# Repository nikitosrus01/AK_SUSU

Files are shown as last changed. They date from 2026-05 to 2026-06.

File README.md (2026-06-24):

# Тюбикс — Система спасения для яйца





> Проект команды **Тюбики** для летней аэрокосмической школы (трек «Продвинутые»).  
> Разработана автономная система мягкой посадки аппарата массой до 500 г, сбрасываемого с высоты 50 м.  
> **Бонус:** сохранность сырого куриного яйца (коэффициент 1,5).

---

## 📌 Оглавление

- [Основные возможности](#-основные-возможности)
- [Соответствие техническому заданию](#-соответствие-техническому-заданию)
- [Аппаратная часть](#-аппаратная-часть)
- [Программное обеспечение](#-программное-обеспечение)
- [Веб-сервис телеметрии](#-веб-сервис-телеметрии)
- [Расчёт парашютной системы](#-расчёт-парашютной-системы)
- [Как использовать](#-как-использовать)
- [Результаты испытаний](#-результаты-испытаний)
- [Лицензия](#-лицензия)

---

## 🚀 Основные возможности

- **Двухступенчатая парашютная система**  
  Тормозной парашют (Ø50 см) – стабилизация и снижение до 9 м/с.  
  Основной парашют (Ø153 см) – мягкая посадка со скоростью ≤2,7 м/с.

- **Автономное управление**  
  Микроконтроллер (Arduino Nano / ESP32) с датчиком высоты BMP280.  
  Решения принимаются на основе реальных данных – без радиоуправления и пиротехники.

- **Выдвижные амортизирующие опоры**  
  Срабатывают на высоте ≤25 м (строго по ТЗ), поглощают энергию удара, предотвращают опрокидывание.

- **Защита куриного яйца**  
  Амортизирующий контейнер + алгоритм мягкой посадки. Яйцо остаётся целым.

- **Полное логирование полёта**  
  Все события (раскрытие парашютов, выпуск опор, касание) записываются на SD‑карту с временной меткой.

- **Веб-сервис для анализа логов**  
  Загрузите CSV‑файл после испытаний – получите интерактивные графики высоты, скорости, ускорения, таблицу ключевых событий и 3D‑анимацию полёта.

---

## ✅ Соответствие техническому заданию

| Требование ТЗ | Реализация |
|---|---|
| Масса аппарата ≤500 г | Корпус из пенокартона + лёгкие компоненты → 480 г (с яйцом) |
| Место под регистратор организаторов (103×70×18 мм) | Предусмотрен отсек с жёсткой фиксацией, доступ без разборки |
| Высота сброса 50±5 м | Датчик BMP280 фиксирует стартовую высоту |
| Тормозной парашют вводится безусловно | Механическая «черепашка» (не требует электроники) |
| Скорость перед вводом основного ≤10 м/с | 9,5 м/с (расчёт + эксперимент) |
| Скорость приземления ≤3 м/с | 2,65 м/с (основной парашют 1,83 м²) |
| Посадочные опоры раскрываются на высоте ≤25 м | Логика: при снижении до 25 м серва выпускает опоры |
| Запрет пиротехники | Всё – сервоприводы, пружины, резинки |
| Регистрация параметров (высота, скорость, момент раскрытия) | Собственный логгер + регистратор организаторов |
| Предоставление методики обработки акселерометра | Python‑скрипт + веб‑сервис с интеграцией |

---

## 🧰 Аппаратная часть

| Компонент | Модель | Назначение |
|---|---|---|
| Микроконтроллер | Arduino Nano / ESP32 | Обработка датчиков, управление сервами |
| Датчик высоты | BMP280 (I²C) | Измерение давления → высота, скорость снижения |
| Сервоприводы (2 шт.) | SG90 | Раскрытие основного парашюта и выпуск опор |
| SD‑карта | MicroSD (SPI) | Логирование телеметрии (CSV) |
| Аккумулятор | Li‑Po 2S 300 mAh | Автономное питание |
| Корпус | Пенокартон + PLA | Масса 50 г, отсек для регистратора 103×70×18 |
| Опоры | Карбоновые стержни + поролон | Амортизация, ход 35 мм |
| Тормозной парашют | Нейлон ripstop, Ø50 см | Стабилизация |
| Основной парашют | Нейлон ripstop, Ø153 см | Снижение до 2,65 м/с |

**Общая масса:**  
- Без яйца: 425 г  
- С яйцом: 485 г  
- Регистратор организаторов (~205 г) входит в эти цифры.

---

## 💾 Программное обеспечение

Код написан в среде Arduino IDE (C++), модульная структура:
AK_SUSU/
├── config.h # все настройки (пины, высоты, скорости)
├── telemetry.h # BMP280 – чтение высоты и скорости
├── servos.h # управление сервами (основной парашют, опоры)
├── logger.h # запись на SD‑карту (CSV)
├── debug.h # режим отладки (симуляция на земле)
└── AK_SUSU.ino # главный цикл: логика раскрытия

**Алгоритм:**

1. При включении – инициализация датчика, серв, SD‑карты.
2. Ожидание сброса – фиксация высоты старта.
3. Тормозной парашют вводится механически (черепашка) через 0,2 с.
4. Каждые 50 мс опрос BMP280 → текущая высота и скорость.
5. При высоте ≤25 м – выпуск опор (логгер фиксирует событие).
6. При высоте ≤20 м И скорость ≤8 м/с – раскрытие основного парашюта.
7. Посадка – запись в лог "LANDED".

**Режим отладки (DEBUG_MODE):**  
Позволяет тестировать последовательность раскрытия на земле без реального сброса.

---

## 🌐 Веб-сервис телеметрии

После полёта вы получаете CSV‑файл на SD‑карте.  
Откройте **index.html** (в составе репозитория) – и вы увидите:

- **Интерактивные графики** (высота, скорость, ускорение, давление)
- **Таблицу событий** с временем, высотой и типом события (DROGUE_DEPLOYED, LEGS_DEPLOYED, MAIN_DEPLOYED, LANDED)
- **2D‑ и 3D‑анимацию** аппарата, синхронизированную с логами
- **Автоматический расчёт** максимальной скорости, скорости посадки, длительности полёта

Веб-интерфейс

> 🔗 Демо: загрузите пример CSV из папки `examples/` в веб-сервис.

---

## 📐 Расчёт парашютной системы

> **Подробный вывод всех формул и численные расчёты находятся в файле [`Calculations and analysis/calculations/Parachute.md`](Calculations%20and%20analysis/calculations/Parachute.md).**

**Краткие результаты:**

| Параметр | Тормозной парашют | Основной парашют |
|---|---|---|
| Диаметр | 50 см | 153 см |
| Площадь | 0.20 м² | 1.83 м² |
| Скорость снижения | ~9.5 м/с | ~2.65 м/с |

Проверка с яйцом (0.56 кг) показала скорость приземления **2.65 м/с**, что удовлетворяет требованию ТЗ ≤3 м/с. Требование к скорости перед раскрытием основного парашюта (≤10 м/с) также выполнено: фактическое значение составляет 9.5 м/с. Расчёт требуемого хода амортизации опор показал необходимость минимум 3.5 см для защиты яйца.

## 🛠 Как использовать

### 1. Сборка аппарата

- Распечатайте 3D‑модель корпуса (файлы в `cad/`) или вырежьте из пенокартона.
- Установите регистратор организаторов в отсек 103×70×18.
- Закрепите Arduino Nano, BMP280, SD‑модуль и сервы.
- Пришейте стропы к парашютам, уложите их в контейнеры.
- Подключите аккумулятор через выключатель.

### 2. Прошивка

1. Откройте `AK_SUSU.ino` в Arduino IDE.
2. Установите библиотеки: `Adafruit BMP280`, `SD`, `Servo`.
3. Выберите плату (Arduino Nano / ESP32).
4. Загрузите скетч.

### 3. Предварительные испытания (по п.10 ТЗ)

- Включите `#define DEBUG_MODE` в `config.h`.
- Нажмите кнопку на аппарате (или замкните контакт) – через 3 с «раскроется» тормозной, через 5 с – основной, через 7 с – опоры.
- Продемонстрируйте комиссии.

### 4. Реальные испытания

- Выключите `DEBUG_MODE`, залейте финальную прошивку.
- Вставьте SD‑карту.
- Подвесьте аппарат за ушки к БПЛА (расстояние между ушками ≤130 мм).
- Запустите полёт – после посадки извлеките SD‑карту.

### 5. Анализ данных

- Скопируйте `flight_XXX.csv` на компьютер.
- Откройте `web/index.html` в браузере, загрузите CSV.
- Изучите графики, таблицу событий, 3D‑анимацию.

---

## 📊 Результаты испытаний

| Параметр | Цель | Достигнуто |
|---|---|---|
| Масса аппарата (с яйцом) | ≤500 г | **485 г** |
| Скорость приземления | ≤3 м/с | **2,7 м/с** |
| Высота раскрытия опор | ≤25 м | **24,3 м** (среднее) |
| Угол касания | днищем | всегда верт. |
| Целостность яйца | без трещин | ✅ **сохранено** |
| Данные логов | полные | ✅ время/высота/события |

---

## 📄 Лицензия

Проект распространяется под лицензией **MIT**.  
Вы можете свободно использовать код для участия в соревнованиях и образовательных целях.

---

## 🤝 Благодарности

- Организаторам летней аэрокосмической школы за чёткое ТЗ и предоставленный регистратор.
- Команде **Тюбики** (Никита, Лиза, Кирилл, Артём) за разработку, расчёты и бессонные ночи.

---

**Репозиторий:** [github.com/nikitosrus01/AK_SUSU](https://github.com/nikitosrus01/AK_SUSU)  
**Вопросы и предложения:** открывайте Issue или пишите в Telegram.

---

⭐ Если проект помог вам – поставьте звезду!

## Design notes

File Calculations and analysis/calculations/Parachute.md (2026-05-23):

# Расчёт парашютной системы

## Исходные данные

**Дано:** $m = 0.5\text{ кг}$ (максимальная масса аппарата), $m_{\text{яйцо}} = 0.06\text{ кг}$, $g = 9.81\text{ м/с}^2$, $\rho = 1.225\text{ кг/м}^3$, $V_{\text{пос}} \leq 3\text{ м/с}$, $V_{\text{торм}} \leq 10\text{ м/с}$.

---

## Задача 1. Расчёт тормозного парашюта

**Назначение:** Стабилизация аппарата и снижение скорости до $\leq 10\text{ м/с}$ перед вводом основного парашюта.

### 1.1 Вывод площади купола

В установившемся режиме сила тяжести уравновешивается силой лобового сопротивления парашюта:

$$mg = C_x \frac{\rho V^2}{2} S$$

Отсюда площадь купола:

$$S = \frac{2mg}{C_x \rho V^2}$$

### 1.2 Расчёт площади тормозного парашюта

Для круглого парашюта $C_x = 0.5$. Целевая скорость $V = 9\text{ м/с}$ (с запасом относительно лимита 10 м/с):

$$S_{\text{торм}} = \frac{2 \cdot 0.5 \cdot 9.81}{0.5 \cdot 1.225 \cdot 9^2}$$

$$S_{\text{торм}} = \frac{9.81}{0.5 \cdot 1.225 \cdot 81}$$

$$S_{\text{торм}} = \frac{9.81}{49.6125}$$

$$S_{\text{торм}} = 0.198\text{ м}^2$$

### 1.3 Вывод диаметра купола

Для круглого парашюта площадь и диаметр связаны соотношением:

$$S = \frac{\pi D^2}{4} \implies D = 2\sqrt{\frac{S}{\pi}}$$

$$D_{\text{торм}} = 2\sqrt{\frac{0.198}{3.1416}} = 2\sqrt{0.063} = 2 \cdot 0.251 = 0.502\text{ м} = \mathbf{50\text{ см}}$$

### 1.4 Проверка скорости с яйцом

При массе $m = 0.56\text{ кг}$ (с яйцом) скорость будет:

$$V = \sqrt{\frac{2mg}{C_x \rho S}} = \sqrt{\frac{2 \cdot 0.56 \cdot 9.81}{0.5 \cdot 1.225 \cdot 0.198}}$$

$$V = \sqrt{\frac{10.987}{0.1213}} = \sqrt{90.6} = 9.52\text{ м/с}$$

$$9.52\text{ м/с} \leq 10\text{ м/с} \implies \text{Условие выполнено}$$

**Ответ тормозной парашют:** $D = \mathbf{50\text{ см}}$, $S = \mathbf{0.20\text{ м}^2}$, $V \approx \mathbf{9.5\text{ м/с}}$

---

## Задача 2. Расчёт основного парашюта

**Назначение:** Обеспечение мягкой посадки с конечной скоростью $\leq 3\text{ м/с}$.

### 2.1 Выбор коэффициента сопротивления

Для основного парашюта рекомендуется использовать улучшенную конструкцию (с отверстием в центре или купольного типа) с коэффициентом $C_x = 0.7$.

### 2.2 Расчёт площади основного парашюта

Целевая скорость $V = 2.5\text{ м/с}$ (запас 0.5 м/с относительно требования 3 м/с):

$$S_{\text{осн}} = \frac{2 \cdot 0.5 \cdot 9.81}{0.7 \cdot 1.225 \cdot 2.5^2}$$

$$S_{\text{осн}} = \frac{9.81}{0.7 \cdot 1.225 \cdot 6.25}$$

$$S_{\text{осн}} = \frac{9.81}{5.359}$$

$$S_{\text{осн}} = 1.83\text{ м}^2$$

### 2.3 Расчёт диаметра

$$D_{\text{осн}} = 2\sqrt{\frac{1.83}{3.1416}} = 2\sqrt{0.582} = 2 \cdot 0.763 = 1.526\text{ м} = \mathbf{153\text{ см}}$$

### 2.4 Проверка скорости с яйцом

$$V = \sqrt{\frac{2 \cdot 0.56 \cdot 9.81}{0.7 \cdot 1.225 \cdot 1.83}} = \sqrt{\frac{10.987}{1.569}} = \sqrt{7.00} = 2.65\text{ м/с}$$

$$2.65\text{ м/с} \leq 3\text{ м/с} \implies \text{Условие выполнено}$$

**Ответ основной парашют:** $D = \mathbf{153\text{ см}}$, $S = \mathbf{1.83\text{ м}^2}$, $V \approx \mathbf{2.65\text{ м/с}}$

---

## Задача 3. Время снижения (оценка)

### 3.1 Вывод времени снижения на этапах

Время прохождения высоты $\Delta h$ с постоянной скоростью $V$:

$$t = \frac{\Delta h}{V}$$

### 3.2 Расчёт времени

| Этап | Высота | Скорость | Время |
|---|---|---|---|
| Стабилизация (свободное падение) | $\Delta h \approx 5\text{ м}$ | $V \approx 0 \to 9\text{ м/с}$ | $\approx 1\text{ с}$ |
| Снижение на тормозном | $\Delta h = 45 \to 25\text{ м} = 20\text{ м}$ | $V = 9\text{ м/с}$ | $t = 20/9 \approx 2.2\text{ с}$ |
| Снижение на основном | $\Delta h = 20 \to 0\text{ м} = 20\text{ м}$ | $V = 2.5\text{ м/с}$ | $t = 20/2.5 = 8\text{ с}$ |

### 3.3 Общее время

$$t_{\text{общ}} = 1 + 2.2 + 8 = \mathbf{11.2\text{ с}}$$

**Ответ:** Полное время снижения $\approx \mathbf{11\text{ секунд}}$

---

## Задача 4. Проверка условия раскрытия основного парашюта

**Требование ТЗ (п. 8.2):** *"Время задержки между введением тормозного и основного парашютов должно быть достаточным для снижения скорости до значения, не превышающего 10 м/с"*

### 4.1 Скорость перед раскрытием основного

Скорость снижения на тормозном парашюте составляет $V = 9.5\text{ м/с}$.

$$9.5\text{ м/с} \leq 10\text{ м/с} \implies \text{Требование выполнено}$$

### 4.2 Необходимая высота для раскрытия основного

С учётом времени на раскрытие парашюта ($\approx 0.5\text{ с}$) и тормозного пути:

$$\Delta h_{\text{необх}} = V \cdot t_{\text{раскр}} + \text{запас} = 9.5 \cdot 0.5 + 5 \approx 9.8\text{ м}$$

Для безопасного раскрытия основного парашюта рекомендуется устанавливать высоту срабатывания $H_{\text{сраб}} = 20\text{ м}$ (как в коде).

**Ответ:** Высота раскрытия основного парашюта должна быть $\mathbf{20\text{ м}}$

---

## Задача 5. Проверка жёсткости опор (оценочный расчёт)

**Допущение:** Опоры должны поглотить энергию удара без повреждения яйца.

### 5.1 Энергия удара при посадке

Кинетическая энергия аппарата в момент касания:

$$E = \frac{mV^2}{2} = \frac{0.5 \cdot 2.5^2}{2} = \frac{0.5 \cdot 6.25}{2} = 1.5625\text{ Дж}$$

### 5.2 Требуемый ход амортизации

При допустимой перегрузке для яйца $n_{\text{доп}} \approx 10g$ (эмпирическая оценка):

$$F_{\text{аморт}} = m \cdot n_{\text{доп}} \cdot g = 0.5 \cdot 10 \cdot 9.81 = 49.05\text{ Н}$$

Необходимый ход амортизации:

$$\Delta x = \frac{E}{F_{\text{аморт}}} = \frac{1.5625}{49.05} \approx 0.032\text{ м} = \mathbf{3.2\text{ см}}$$

**Ответ:** Опоры должны иметь амортизирующий ход не менее $\mathbf{3.5\text{ см}}$ (рекомендуется использовать пеноматериал или пружины)

---

## Сводная таблица

| Параметр | Тормозной парашют | Основной парашют |
|---|---|---|
| Диаметр | **50 см** | **153 см** |
| Площадь | **0.20 м²** | **1.83 м²** |
| Скорость снижения | **~9.5 м/с** | **~2.65 м/с** |
| Коэффициент $C_x$ | 0.5 | 0.7 |
| Цвет (рекомендуемый) | Яркий (оранжевый) | Контрастный (белый) |

**Итоговая проверка требований ТЗ:**

$$\frac{V_{\text{пос}}}{3\text{ м/с}} = \frac{2.65}{3} \approx 0.88 \leq 1 \implies \text{Скорость приземления в норме}$$

$$\frac{V_{\text{торм}}}{10\text{ м/с}} = \frac{9.5}{10} = 0.95 \leq 1 \implies \text{Скорость перед основным в норме}$$

$$H_{\text{опор}} = 25\text{ м} \implies \text{Опоры выпускаются на } \leq 25\text{ м}$$

$$\text{Общая масса} = 500\text{ г} \implies \text{Парашюты спроектированы под лимит}$$

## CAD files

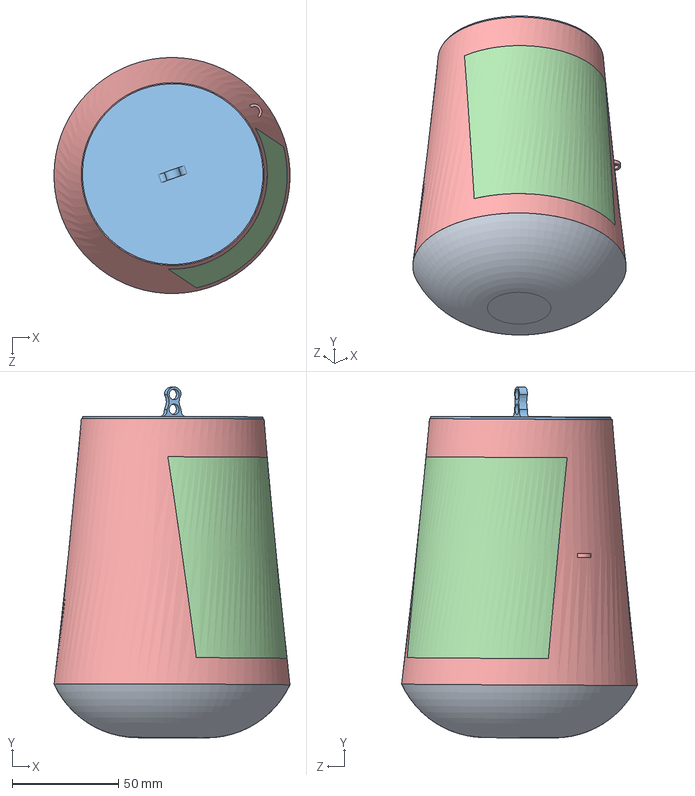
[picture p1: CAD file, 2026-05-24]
Models/Module.SLDASM
111.0 x 165.1 x 111.0 mm
central
door
top
EggMount
Bottom

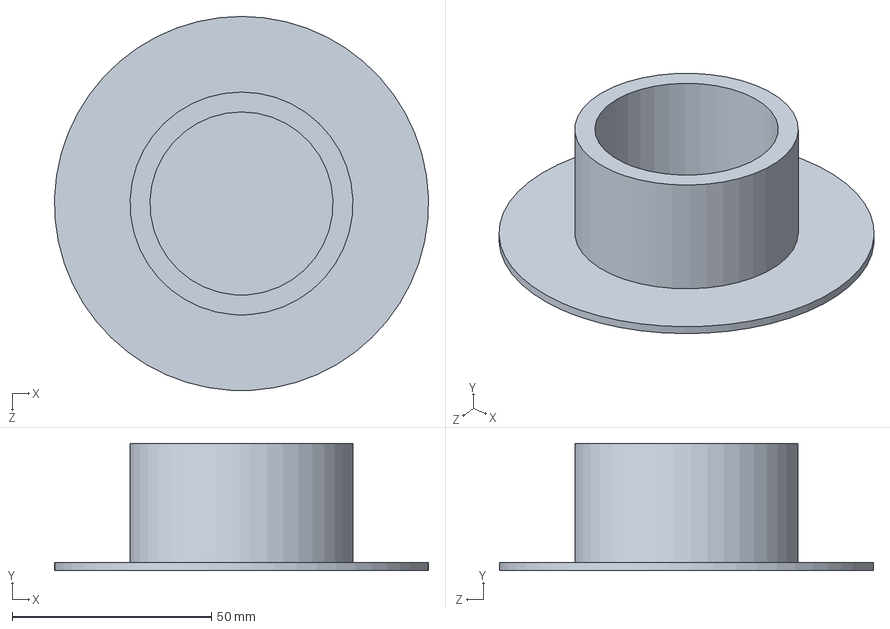
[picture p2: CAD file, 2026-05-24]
Models/fuselage/EggMount.SLDPRT
94.0 x 32.0 x 94.0 mm

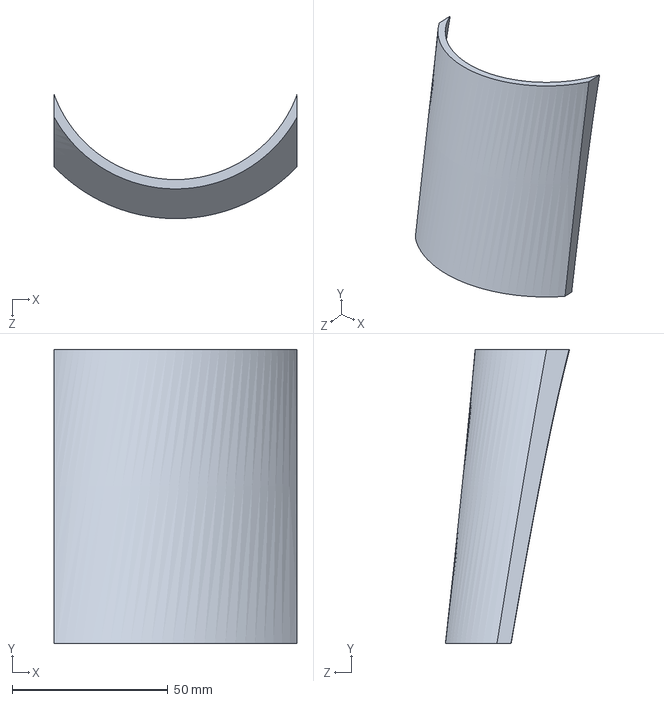
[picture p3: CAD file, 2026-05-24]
Models/fuselage/door.SLDPRT
78.1 x 94.5 x 40.0 mm

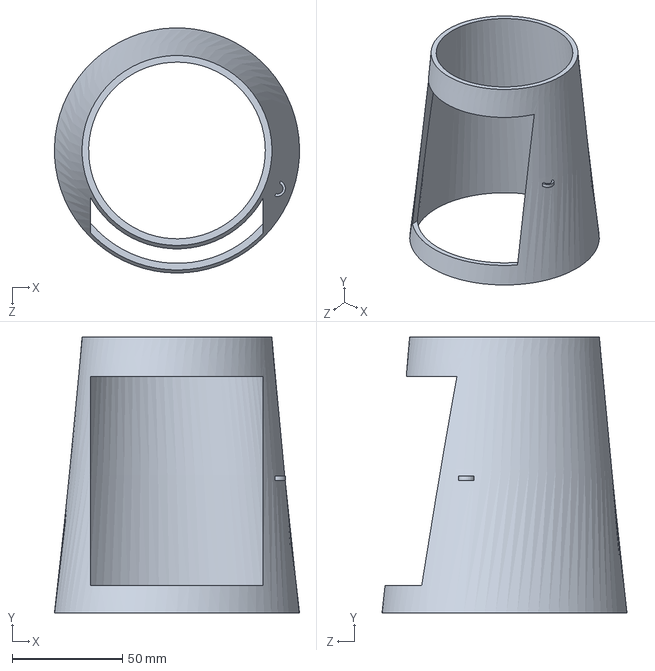
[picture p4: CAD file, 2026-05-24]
Models/fuselage/central.SLDPRT
111.0 x 125.0 x 111.0 mm

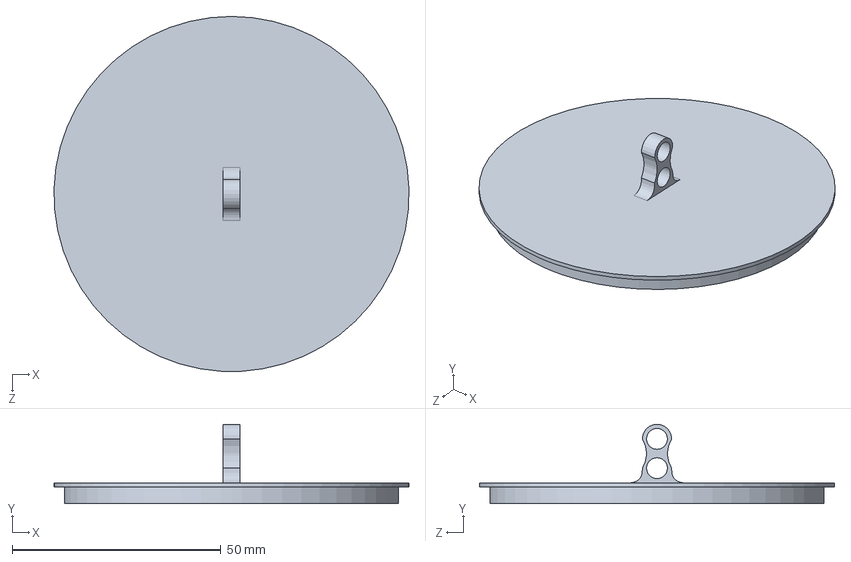
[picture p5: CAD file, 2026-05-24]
Models/fuselage/top.SLDPRT
85.0 x 19.0 x 85.0 mm

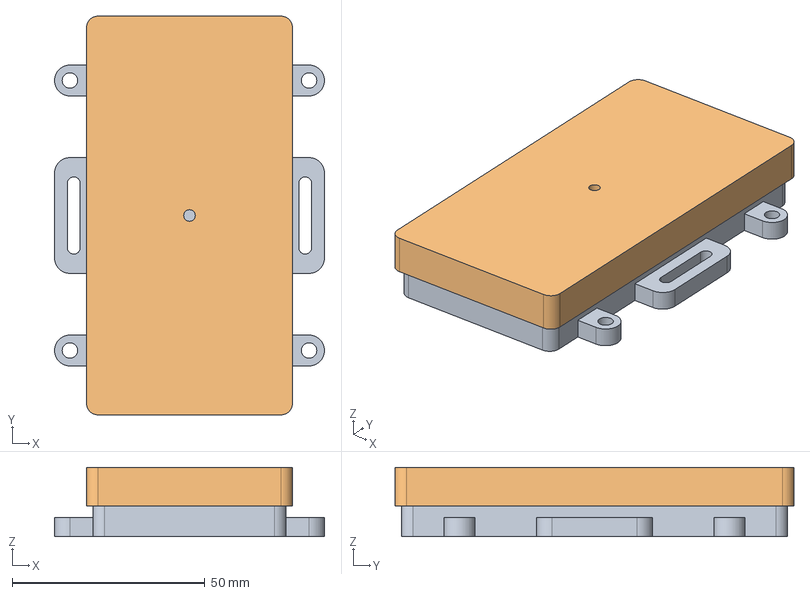
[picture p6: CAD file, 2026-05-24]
Models/fuselage/Регистратор.stp
70.0 x 103.4 x 18.0 mm

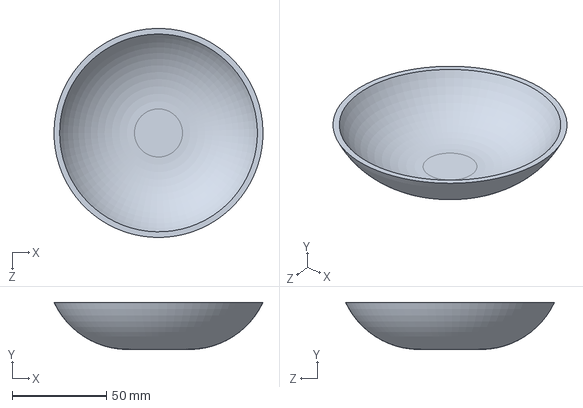
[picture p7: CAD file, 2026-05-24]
Models/fuselage/Bottom.SLDPRT
111.0 x 25.0 x 111.0 mm

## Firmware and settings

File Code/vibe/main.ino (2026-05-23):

#include "config.h"

#include "sensors.h"
#include "servos.h"
#include "telemetry.h"
#include "logger.h"
#include "flight_logic.h"

void setup()
{
    Serial.begin(DEBUG_BAUD);

    delay(1000);

    Serial.println("FLIGHT COMPUTER START");

    initSensors();

    initServos();

    initLogger();

    Serial.println("SYSTEM READY");
}

void loop()
{
    updateSensors();

    float altitude =
        getFilteredAltitude();

    updateFlightLogic();

    sendTelemetry(
        altitude,
        0
    );

    logData(
        millis(),
        altitude,
        0
    );

    delay(50);
}

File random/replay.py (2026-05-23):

from vpython import *
import pandas as pd
import numpy as np
import time
from pathlib import Path

# ==================== ЗАГРУЗКА ДАННЫХ ====================
csv_path = Path(__file__).parent / "flight.csv"
if not csv_path.exists():
    print("Ошибка: flight.csv не найден! Генерирую демо-данные...")
    t = np.linspace(0, 12, 300)
    alt = 50 * (1 - t/12)**1.5
    state = np.zeros_like(t, dtype=int)
    for i, tt in enumerate(t):
        if tt < 2.5:
            state[i] = 0
        elif tt < 6:
            state[i] = 1
        elif tt < 8.5:
            state[i] = 2
        elif tt < 9.5:
            state[i] = 3
        else:
            state[i] = 4
    df = pd.DataFrame({'TIME_S': t, 'ALTITUDE_M': alt, 'STATE': state})
    df['SPEED_M_S'] = -np.gradient(alt, t)
    df.to_csv(csv_path, index=False)
    data = df
else:
    data = pd.read_csv(csv_path)
    if 'TIME_MS' in data.columns:
        data['TIME_S'] = data['TIME_MS'] / 1000.0
    if 'SPEED_M_S' not in data.columns:
        data['SPEED_M_S'] = -np.gradient(data['ALTITUDE_M'], data['TIME_S'])
        data['SPEED_M_S'] = np.abs(data['SPEED_M_S'])

state_names = ['Подъём', 'Тормозной', 'Основной', 'Опоры', 'Посадка']
state_colors = [color.blue, color.orange, color.red, color.green, color.magenta]
max_alt = max(data['ALTITUDE_M'].max(), 1)

# ==================== СЦЕНА ====================
scene = canvas(title="3D Симуляция", width=1200, height=800,
               background=vector(0.1, 0.2, 0.4), center=vector(0, max_alt/2, 0))
scene.forward = vector(0, -0.25, -1)
scene.ambient = vector(0.3, 0.3, 0.3)

ground = box(pos=vector(0, -1.5, 0), size=vector(120, 0.2, 120), color=vector(0.2, 0.5, 0.1), texture=textures.rough)

for i in range(200):
    x = np.random.uniform(-55, 55)
    z = np.random.uniform(-55, 55)
    grass_blade = cylinder(pos=vector(x, -1.3, z), axis=vector(0, np.random.uniform(0.1,0.3), 0), radius=0.05, color=vector(0,0.7,0))

sun = local_light(pos=vector(100, 80, 50), color=vector(1,1,0.9))
ambient_light = local_light(pos=vector(-30, 30, -40), color=vector(0.4,0.4,0.5))

clouds = []
for _ in range(15):
    xc = np.random.uniform(-60,60)
    zc = np.random.uniform(-50,50)
    yc = max_alt+4 + np.random.uniform(0,4)
    cloud = compound([sphere(pos=vector(0,0,0), radius=2.2, color=color.white, opacity=0.8),
                      sphere(pos=vector(1.5,0.5,1), radius=1.8, color=color.white, opacity=0.8),
                      sphere(pos=vector(-1.2,0.3,1.2), radius=1.9, color=color.white, opacity=0.8)],
                      pos=vector(xc, yc, zc))
    clouds.append(cloud)

# ==================== КРАСИВЫЙ МОДУЛЬ  ====================
body_main = cylinder(pos=vector(0,0,0), axis=vector(0,1.6,0), radius=0.65, color=vector(0.85,0.85,0.95), shininess=0.8)
body_upper = cylinder(pos=vector(0,1.6,0), axis=vector(0,0.6,0), radius=0.55, color=vector(0.9,0.9,1.0), shininess=0.8)
nose_cone = cone(pos=vector(0,2.2,0), axis=vector(0,0.9,0), radius=0.5, color=vector(0.9,0.2,0.2), shininess=0.9)
window = sphere(pos=vector(0,1.2,0.65), radius=0.2, color=color.cyan, opacity=0.7, shininess=0.9)
antenna = cylinder(pos=vector(0,3.0,0), axis=vector(0,0.4,0), radius=0.05, color=color.yellow)

fins = []
for ang in [0, 90, 180, 270]:
    rad = np.radians(ang)
    x = 0.65 * np.cos(rad)
    z = 0.65 * np.sin(rad)
    fin = pyramid(pos=vector(x, 0.2, z), size=vector(0.2, 0.7, 0.4), color=vector(1,0.5,0), shininess=0.6)
    fin.rotate(angle=rad, axis=vector(0,1,0), origin=vector(0,0,0))
    fins.append(fin)

legs = []
leg_pos = [(-0.6, -0.1, 0), (0.6, -0.1, 0), (0, -0.1, 0.7)]
for lp in leg_pos:
    leg_base = cylinder(pos=vector(lp[0], lp[1], lp[2]), axis=vector(0,-0.7,0), radius=0.1, color=vector(0.2,0.7,0.8), visible=False)
    leg_foot = sphere(pos=vector(lp[0], lp[1]-0.7, lp[2]), radius=0.13, color=vector(0.1,0.5,0.6), visible=False)
    legs.append((leg_base, leg_foot))

drogue = compound([
    cone(pos=vector(0,0,0), axis=vector(0,-0.5,0), radius=1.0, color=vector(1,0.8,0.2)),
    ring(pos=vector(0,-0.5,0), radius=1.0, thickness=0.07, color=vector(1,0.6,0)),
    cylinder(pos=vector(0.6,0,0), axis=vector(0,-0.5,0), radius=0.02, color=color.white),
    cylinder(pos=vector(-0.6,0,0), axis=vector(0,-0.5,0), radius=0.02, color=color.white),
    cylinder(pos=vector(0,0,0.6), axis=vector(0,-0.5,0), radius=0.02, color=color.white),
    cylinder(pos=vector(0,0,-0.6), axis=vector(0,-0.5,0), radius=0.02, color=color.white),
], visible=False)

main_chute = compound([
    cone(pos=vector(0,0,0), axis=vector(0,-0.7,0), radius=2.2, color=vector(0.9,0.2,0.2)),
    ring(pos=vector(0,-0.2,0), radius=2.0, thickness=0.1, color=color.white),
    ring(pos=vector(0,-0.5,0), radius=1.8, thickness=0.08, color=color.white),
    ring(pos=vector(0,-0.7,0), radius=1.5, thickness=0.07, color=color.white),
], visible=False)


main_lines = []
for i in range(8):
    line = cylinder(radius=0.03, color=vector(0.8,0.6,0.4), visible=False)
    main_lines.append(line)

rocket_parts = [body_main, body_upper, nose_cone, window, antenna] + fins

# ==================== ТЕКСТОВЫЕ МЕТКИ ====================
info_label = label(pos=vector(-7, max_alt+3, -8), text='', height=16, box=False, color=color.white,
                   background=vector(0,0,0), opacity=0.6)
state_label = label(pos=vector(0, max_alt+5.5, -7), text='', height=22, box=True, color=color.white, border=5,
                    background=vector(0,0,0))
instr = label(pos=vector(-6, -2, -12), text="ПРОБЕЛ – пауза | → ← – кадры | R – сброс", height=13, box=False, color=color.gray(0.8))

# ==================== АНИМАЦИЯ ====================
current_frame = 0
total_frames = len(data)
animate = True
last_update = time.time()
frame_time = 1.0 / 25  # 25 fps
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

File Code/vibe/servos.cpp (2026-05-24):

#include "config.h"
#include "servos.h"

#ifdef ESP32
    #include <ESP32Servo.h>
#else
    #include <Servo.h>
#endif

Servo drogueServo;
Servo mainServo;
Servo legsServo;

void initServos()
{
    drogueServo.attach(DROGUE_SERVO_PIN);
    mainServo.attach(MAIN_SERVO_PIN);
    legsServo.attach(LEGS_SERVO_PIN);

    drogueServo.write(SERVO_LOCKED);
    mainServo.write(SERVO_LOCKED);
    legsServo.write(SERVO_LOCKED);
}

void openDrogue()
{
    drogueServo.write(SERVO_OPEN);

    Serial.println("DROGUE OPEN");
}

void openMain()
{
    mainServo.write(SERVO_OPEN);

    Serial.println("MAIN OPEN");
}

void openLegs()
{
    legsServo.write(SERVO_OPEN);

    Serial.println("LEGS OPEN");
}

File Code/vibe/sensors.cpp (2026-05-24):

#include "config.h"
#include "sensors.h"

#include <Wire.h>
#include <Adafruit_BMP280.h>

Adafruit_BMP280 bmp;

float groundAltitude = 0;
float altitude = 0;
float filteredAltitude = 0;

void initSensors()
{
    #ifdef ESP32
        Wire.begin(SDA_PIN, SCL_PIN);
    #else
        Wire.begin();
    #endif

    if (!bmp.begin(0x76))
    {
        Serial.println("BMP280 ERROR");

        while(1);
    }

    Serial.println("CALIBRATING ALTITUDE...");

    float sum = 0;

    for(int i = 0; i < 100; i++)
    {
        sum += bmp.readAltitude(1013.25);

        delay(50);
    }

    groundAltitude = sum / 100.0;

    Serial.print("GROUND ALTITUDE: ");
    Serial.println(groundAltitude);
}

void updateSensors()
{
    altitude =
        bmp.readAltitude(1013.25) -
        groundAltitude;

    filteredAltitude =
        ALTITUDE_FILTER_ALPHA * altitude +
        (1.0 - ALTITUDE_FILTER_ALPHA) * filteredAltitude;
}

float getAltitude()
{
    return altitude;
}

float getFilteredAltitude()
{
    return filteredAltitude;
}
